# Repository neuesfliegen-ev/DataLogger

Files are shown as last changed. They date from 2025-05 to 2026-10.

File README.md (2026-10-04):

# 🛩️ Flight Data Logger

This project is a **Flight Data Logger** designed for UAVs and model aircraft. It logs sensor and GPS data at 1 Hz to an SD card in CSV format and streams live telemetry to a server over a cellular (3G/4G) link. The system uses an IMU, a barometric sensor and a GPS module, and shows live status updates on an OLED screen.

## 📦 Features

- Logs data to SD card in `.csv` format
- Captures:
  - 9-axis IMU data (acceleration, gyroscope, magnetometer)
  - Barometric pressure, altitude and temperature
  - GPS coordinates, altitude, speed and satellite count
- OLED display for live status updates
- **Live telemetry over cellular**: an ESP32 gateway forwards data to a web server through a SIM7600 modem (see [Live Telemetry](#-live-telemetry-esp32--sim7600))
- Live dashboard for the telemetry data
- Modular and extensible design for future sensor integration

## 🧠 Core Components

| Component | Description |
|---|---|
| **Arduino** | Primary microcontroller (Nano 33 BLE Sense REV2): sensors, SD logging, OLED |
| **ESP32** | Telemetry gateway between the Arduino and the cellular modem |
| **SIM7600** | Cellular modem (with SIM card), controlled by AT commands over UART |
| **BMI270_BMM150** | 9-DOF IMU (acceleration, gyroscope, magnetometer) |
| **LPS22HB** | Barometric pressure sensor |
| **TinyGPS++** | GPS data parser |
| **SH1106 OLED** | I2C 128x64 screen for live feedback |
| **SD Card Module**  | Stores `.csv` data logs |
| **Voltage Divider** | Scales down battery voltage for safe ADC reading |

---

## 📡 Live Telemetry (ESP32 + SIM7600)

Code: [`esp32SimNano.ino`](esp32SimNano.ino)

```
Arduino Nano ──I2C (JSON frames)──► ESP32 ──UART (AT commands)──► SIM7600 ──HTTP POST──► Server ──► Dashboard
     ▲                                │
     └────── READY / ACK (GPIO) ──────┘
```

- **Arduino → ESP32:** the ESP32 runs as an I2C slave (address `0x42`) and receives each data frame as a JSON payload.
- **Handshake:** two GPIO lines coordinate the transfer:
  - `READY` (ESP32 → Nano, GPIO 4): high when the modem is up and the ESP32 can accept a new frame.
  - `ACK` (ESP32 → Nano, GPIO 5): high when the last frame was delivered successfully (HTTP 200).
- **ESP32 → SIM7600:** UART2 at 115200 baud (ESP32 TX = GPIO 17, RX = GPIO 16). On startup the ESP32:
  1. waits until the modem answers `AT`
  2. disables echo (`ATE0`)
  3. opens the network (`AT+NETOPEN`)
  4. starts an HTTP session (`AT+HTTPINIT`, recovering with `AT+HTTPTERM` if a session is stuck)
  5. sets the server URL and `application/json` content type (`AT+HTTPPARA`)
- **Sending:** each frame is uploaded with `AT+HTTPDATA` and sent as an HTTP POST (`AT+HTTPACTION=1`). The ESP32 then waits for an HTTP 200 response.
- **Health check:** the ESP32 polls the modem with `AT` every 200 ms and updates the `READY` line.
- **Modes:** the payload carries a `"mode"` field (`REALTIME` or `BATCH`), which the ESP32 parses.

---

## 🔧 Circuit Diagram

[Wiring diagram](Datenlogger_Files/Datalogger_schematic%20v2.pdf)

> Note: the schematic still shows a 430 Ω resistor in the voltage divider. Use **510 Ω** as described below.

---

## 🔋 ADC Voltage Divider

To safely read the battery voltage with the Arduino's 3.3 V ADC pin, use the following voltage divider:

- **Input voltage**: up to 4.2 V (LiPo 1S max)
- **Top resistor (battery side)**: 510 Ω
- **Bottom resistor (to GND, ADC reads across it)**: 1.8 kΩ

### 📐 Voltage Divider Calculation

```
Vout = Vin × R_bottom / (R_top + R_bottom)
     = 4.2 V × 1800 / (510 + 1800)
     ≈ 3.27 V
```

---

## 📂 Data Format

Logged data is stored as a CSV file (`log.csv`) with the following headers:

```
timestamp,accX,accY,accZ,gyroX,gyroY,gyroZ,magX,magY,magZ,
latitude,longitude,gpsAltitude,Speed,SatCount,roll,pitch,yaw,
pressure,temperature,paltitude
```

Example row:

```
1542,-0.01,0.02,9.81,0.01,-0.02,0.00,30.12,11.23,-45.66,
52.5200,13.4050,120.5,10.4,9,0,0,0,100.3,25.5,132.2
```

---

## 🛠️ Getting Started

### 🔌 Wiring

- Connect sensors and modules via I2C/SPI/Serial as per the diagram.
- Ensure GPS is connected to `Serial1` (typically `TX`/`RX` on the Arduino). (IMPORTANT)
- For telemetry: connect the Arduino to the ESP32 over I2C plus the `READY`/`ACK` lines, and the ESP32 to the SIM7600 over UART (pins above). Insert an active SIM card.
- Insert a **FAT32-formatted SD card**.

### 🧪 Uploading

1. Install dependencies (Arduino):
   - `Arduino_BMI270_BMM150`
   - `Arduino_LPS22HB`
   - `TinyGPSPlus`
   - `U8g2`
2. Compile and upload the main sketch to the Arduino.
3. Upload `esp32SimNano.ino` to the ESP32 (ESP32 board package, uses `Wire` and `HardwareSerial`). Set the server URL in `initSIM7600()` if needed.
4. Open the Serial Monitor at **115200 baud** to see real-time debug info (the ESP32 also echoes modem responses there).

---

## 📊 OLED Display

The OLED shows system status:
- Sensor initialization
- GPS satellite count
- Errors during SD or sensor setup
- Team number

> To keep the display clear and reduce power, messages are brief and limited to startup and GPS updates.

---

## 🧩 Planned Improvements

- Add orientation calculation (roll, pitch, yaw)
- Support logging at configurable rates (5 Hz, 10 Hz)
- Add battery voltage and current sensors

---

## 👨‍💻 Credits

- Developed by the **Neues Fliegen Avionics Team**
- Based on libraries by Arduino, Adafruit and Mikal Hart (TinyGPS++)

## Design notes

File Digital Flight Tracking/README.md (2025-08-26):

# 3D Flight Viewer

An interactive 3D flight path visualization tool that displays animated aircraft flight paths with real-time attitude data, G-force analysis, and speed visualization. [Example video is shot using "flight6.CSV"]

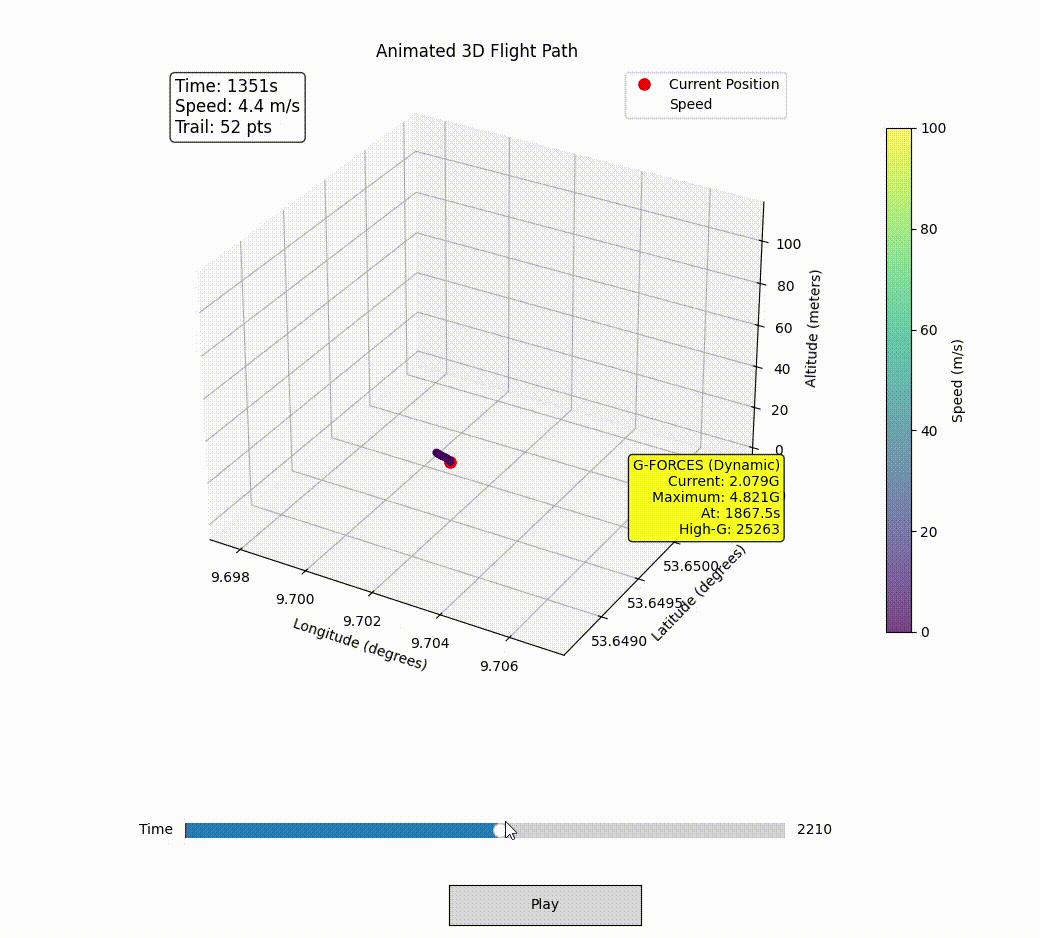
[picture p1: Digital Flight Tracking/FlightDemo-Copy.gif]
GIF


## Features

- **Interactive 3D Animation**: Real-time flight path with speed-colored trail
- **Flight Controls**: Play/pause, time slider for navigation
- **Attitude Analysis**: Roll, pitch, yaw calculations with aviation standards
- **G-Force Monitoring**: Dynamic G-force analysis with high-G event detection
- **Multiple Data Sources**: Support for various flight data formats
- **Click Interaction**: Click on flight path to view detailed flight parameters

## Prerequisites

### Required Software
- **Python 3.7+** (recommended: Python 3.9 or newer)
- **IDE Options** (any of these work well):
  - Visual Studio Code
  - PyCharm
  - Windsurf IDE
  - Jupyter Notebook
  - Any Python-compatible IDE

### Dependencies
Install the required Python packages:

```bash
pip install -r requirements.txt
```

**Required packages:**
- `pandas>=1.3.0` - Data manipulation and analysis
- `numpy>=1.20.0` - Numerical computations
- `matplotlib>=3.3.0` - 3D plotting and animation
- `openpyxl>=3.0.0` - Excel file support
- `pyglet>=1.5.0` - Graphics library

## Installation

1. **Clone or download** the flight_viewer directory
2. **Navigate to the flight_viewer folder** in your terminal/command prompt
3. **Install dependencies:**
   ```bash
   pip install -r requirements.txt
   ```

## Usage

### Basic Usage (Default Flight)
```bash
python animated_3d_viewer.py
```
This runs the default flight data (`ATA-Flight2.CSV`).

### Run Specific Flight Files
You can specify different flight files by adding the filename:

```bash
python animated_3d_viewer.py [filename.CSV]
```

### Available Example Flights
The following flight files are included:

```bash
# Team flights
python animated_3d_viewer.py flight1.CSV      # Default
python animated_3d_viewer.py flight2.CSV
python animated_3d_viewer.py flight3.CSV
python animated_3d_viewer.py flight4.CSV
python animated_3d_viewer.py flight5.CSV
python animated_3d_viewer.py flight6.CSV
```

## Required CSV Format

Your flight data CSV must contain these columns:
- `timestamp` - Time in milliseconds
- `latitude` - GPS latitude in degrees
- `longitude` - GPS longitude in degrees
- `altitude` or `gpsAltitude` - Altitude in meters

**Optional columns for enhanced features:**
- `accX`, `accY`, `accZ` - Accelerometer data (G-units)
- `gyroX`, `gyroY`, `gyroZ` - Gyroscope data (degrees/second)

## Controls

### Animation Controls
- **Play/Pause Button** - Start/stop the animation
- **Time Slider** - Drag to jump to any point in the flight
- **Mouse Click** - Click on flight path points to view detailed data

### Keyboard Shortcuts
- **Close Window** - End the visualization

## Flight Data Display

The viewer shows:
- **Current Position** - Red marker showing aircraft location
- **Speed Trail** - Color-coded trail (51 points) showing recent flight path
  - Blue/Purple = Slower speeds
  - Green/Yellow = Medium speeds  
  - Red = Higher speeds
- **Flight Info Panel** - Current time, speed, and trail length
- **G-Force Panel** - Real-time and maximum G-force data
- **Clickable Points** - Click any trail point for detailed flight parameters

## Performance Features

- **3x Speed Animation** - Fast playback through flight data
- **Optimized Rendering** - Reduced lag with efficient trail rendering
- **Smart Data Sampling** - Shows every 6th data point for smooth performance

## Troubleshooting

### File Not Found
```
Error: File 'filename.CSV' not found.
```
- Ensure you're running the command from the `flight_viewer` directory
- Check that the CSV file exists in the same folder
- Use the exact filename (case-sensitive)

### Missing Columns
The program will show available columns if required ones are missing:
```
Available columns: ['col1', 'col2', ...]
Missing required column 'latitude'. Looked for: ['latitude']
```

### Performance Issues
- Close other applications to free up system resources
- Try a smaller flight file for testing
- Ensure your graphics drivers are up to date

## File Structure

```
flight_viewer/
├── animated_3d_viewer.py    # Main application
├── data_loader.py           # CSV/Excel file reading
├── requirements.txt         # Python dependencies
├── README.md                # This documentation
├── flight1.CSV              # Default flight data
├── flight2.CSV              # Example flight files
├── flight3.CSV              # ...
├── flight4.CSV              # ...
├── flight5.CSV              # ...
├── flight6.CSV              # ...
└── [other flight files]     # Additional examples
```

## Example Commands

```bash
# Run with default settings
python animated_3d_viewer.py

# Run specific team flights
python animated_3d_viewer.py flight6.CSV
python animated_3d_viewer.py flight4.CSV

# Run your own flight data
python animated_3d_viewer.py my_flight_data.CSV
```

## Technical Details

- **Coordinate System**: Uses GPS coordinates (latitude, longitude, altitude)
- **Animation Speed**: 3x real-time with 8ms frame intervals
- **Trail Length**: 51 points with speed-based coloring
- **Attitude Calculation**: Team 0 configuration with aviation standards
- **G-Force Analysis**: Dynamic G-force with gravity compensation

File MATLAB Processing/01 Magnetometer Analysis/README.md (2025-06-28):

# Application of a Kalman Filter for robustness and precision

The following program can be obtained running "A00_Kalman_Filter_TXTs.m", part of the project "01 Final Analysis \ 00 Ideal Spherical Calibration". It includes hard-iron and soft-iron corrections, and accounts for severe magnetic field spikes possibly caused by temporary surrounding objects.

The data used to make the analysis is transferred directly from the USB powering the Arduino, and captured through a simple Windows PowerShell program, "00_ReadUSB_toTxt.ps1". The .ino file is also adapted for this purpose and all necessary files can be found in the folder "02 General Purpose Programs".

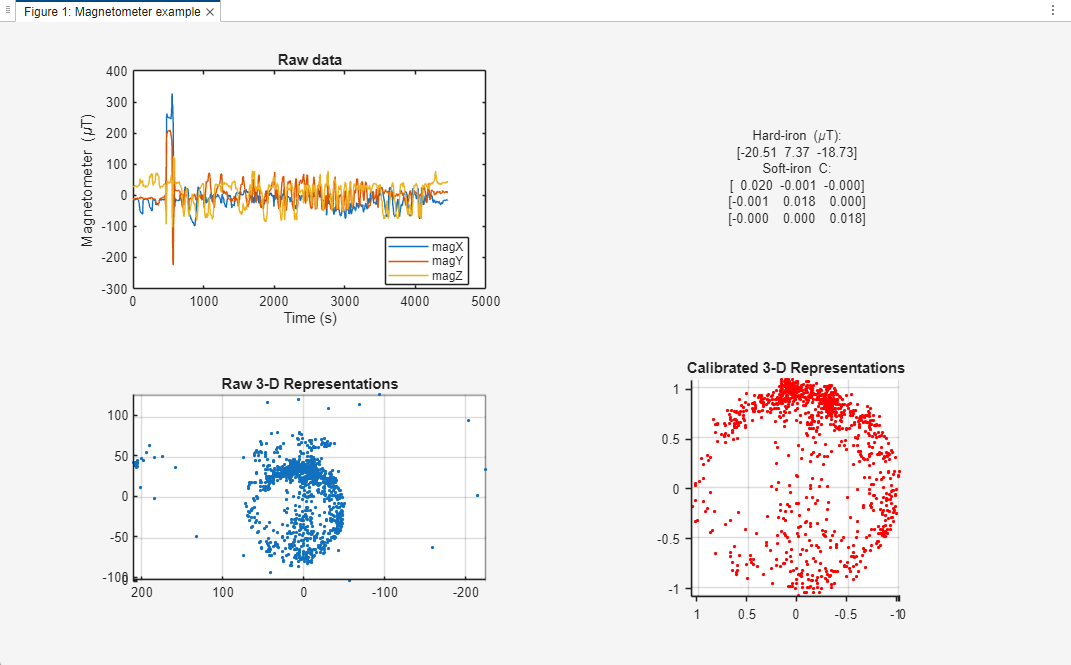
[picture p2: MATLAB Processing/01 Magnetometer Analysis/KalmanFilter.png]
Magnetometer


# Suggested Calibration Procedure

The most realistic and somewhat accurate calibrations are rather the complicated Six-Axis Calibration or the Two-Axis Calibration. The latter still leads to fairly accurate measurements, and is advisable for the competition if "yaw" isn't a critical quantity.

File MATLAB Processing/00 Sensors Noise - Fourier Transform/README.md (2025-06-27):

# Fourier Transform for noise analysis

The following data can be obtained running the main program 'A02_Multiple_SensorData_Analysis'. All other files are functions and must be inside the same folder (including the Excel sheet).

## 📌 Original Signals

Below are the unmodified signals, recorded for 8hs without movement (stationary data collection).

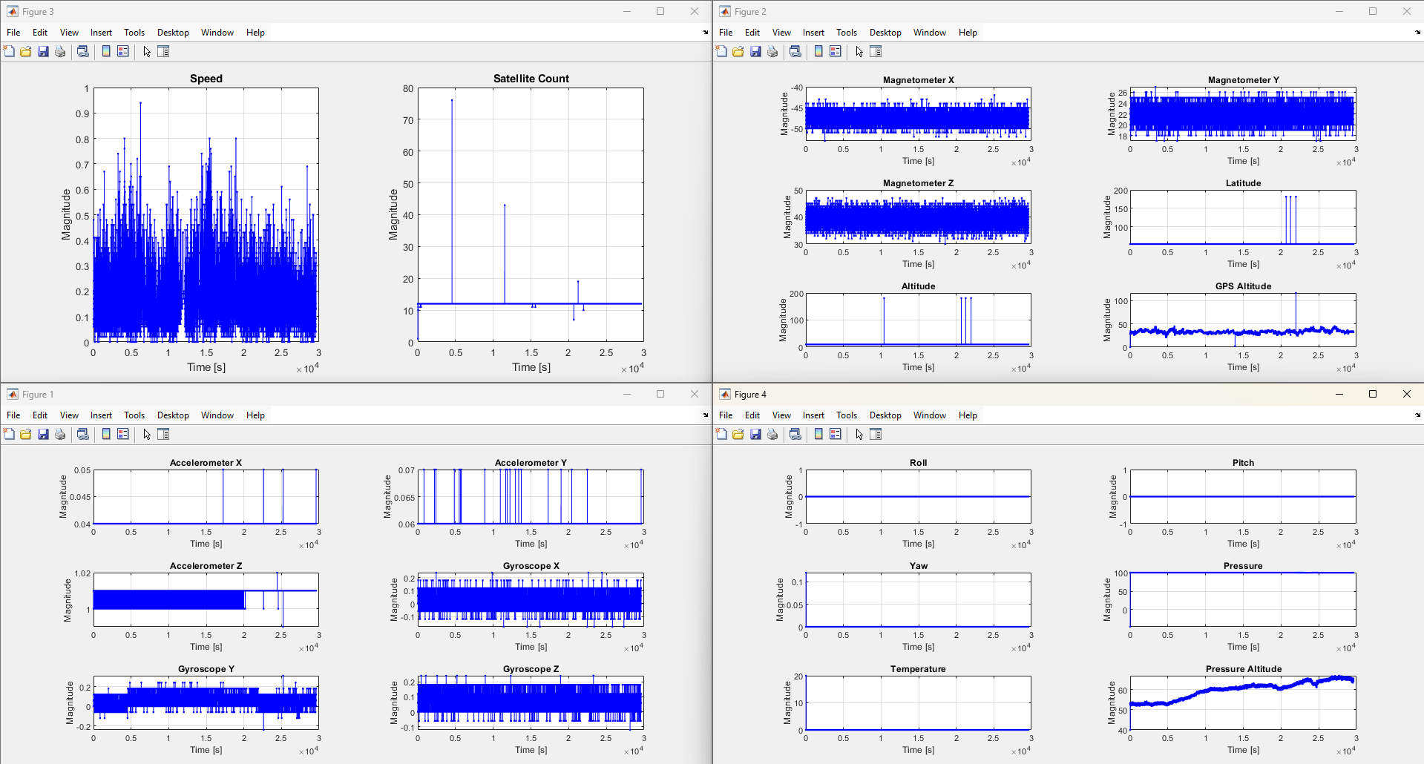
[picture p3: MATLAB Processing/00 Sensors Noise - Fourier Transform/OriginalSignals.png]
Original


## 📌 Fourier Transforms of the signals

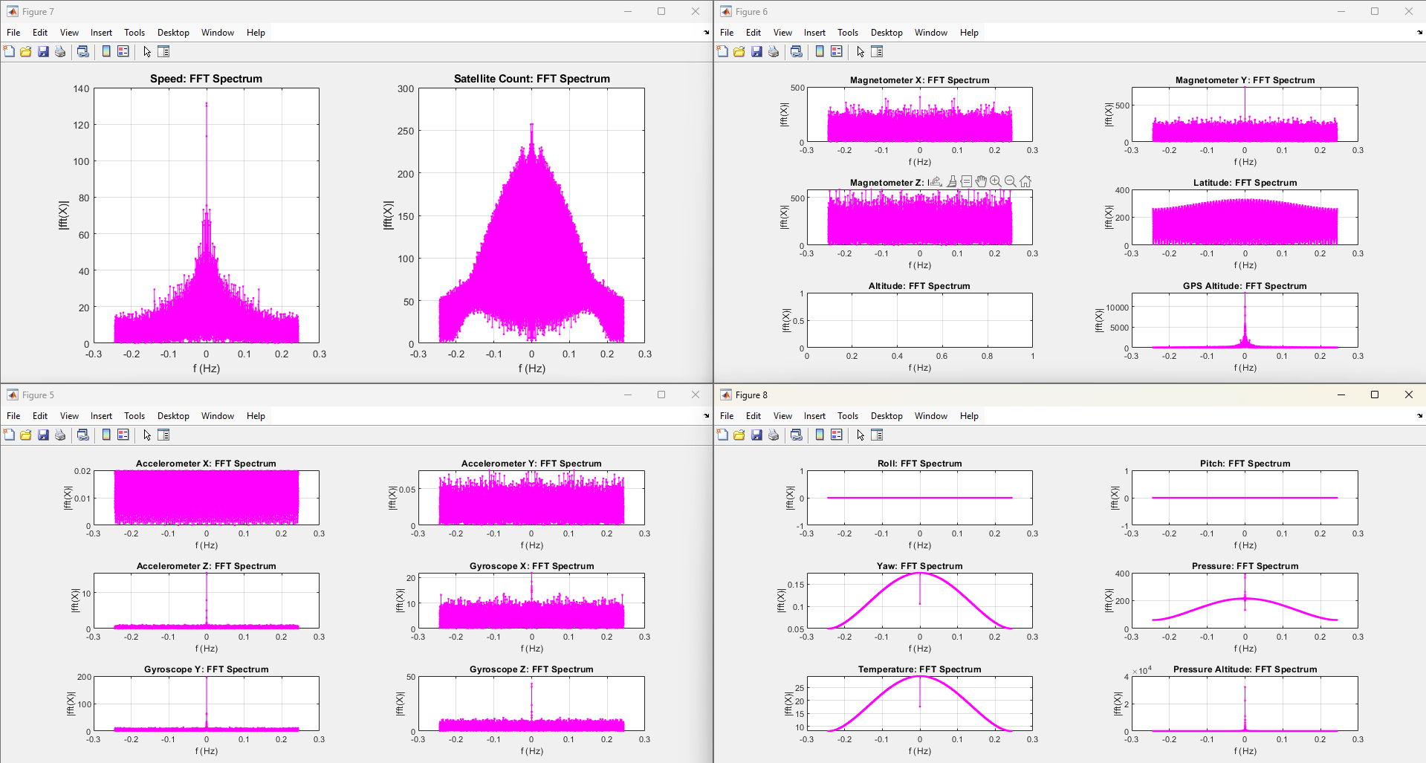
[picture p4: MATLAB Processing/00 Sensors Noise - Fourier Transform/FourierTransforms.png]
FFT


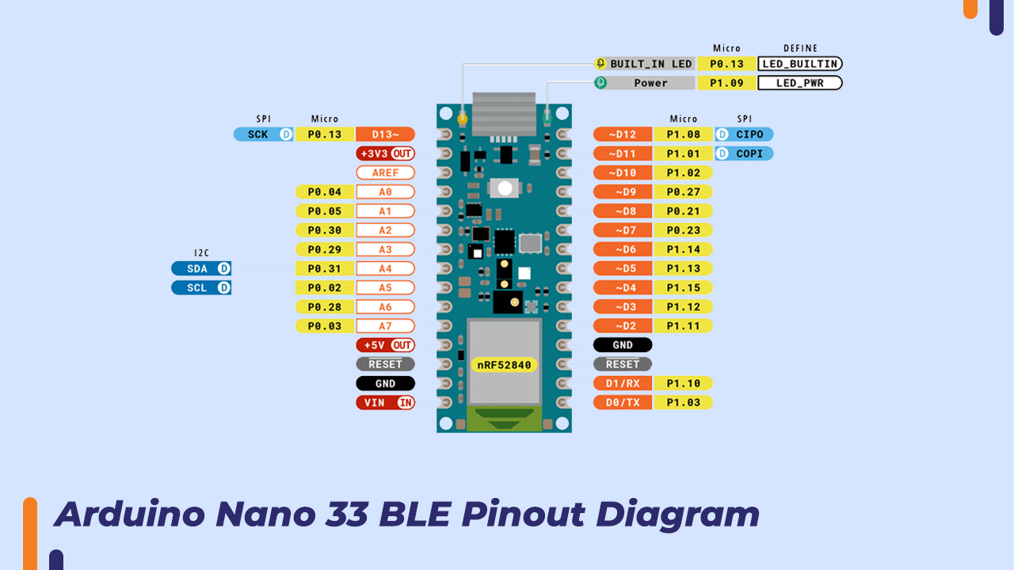
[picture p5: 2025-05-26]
Documentation/Arduino-Nano-33-BLE-Sense-REV2-pinout-diagram.jpg

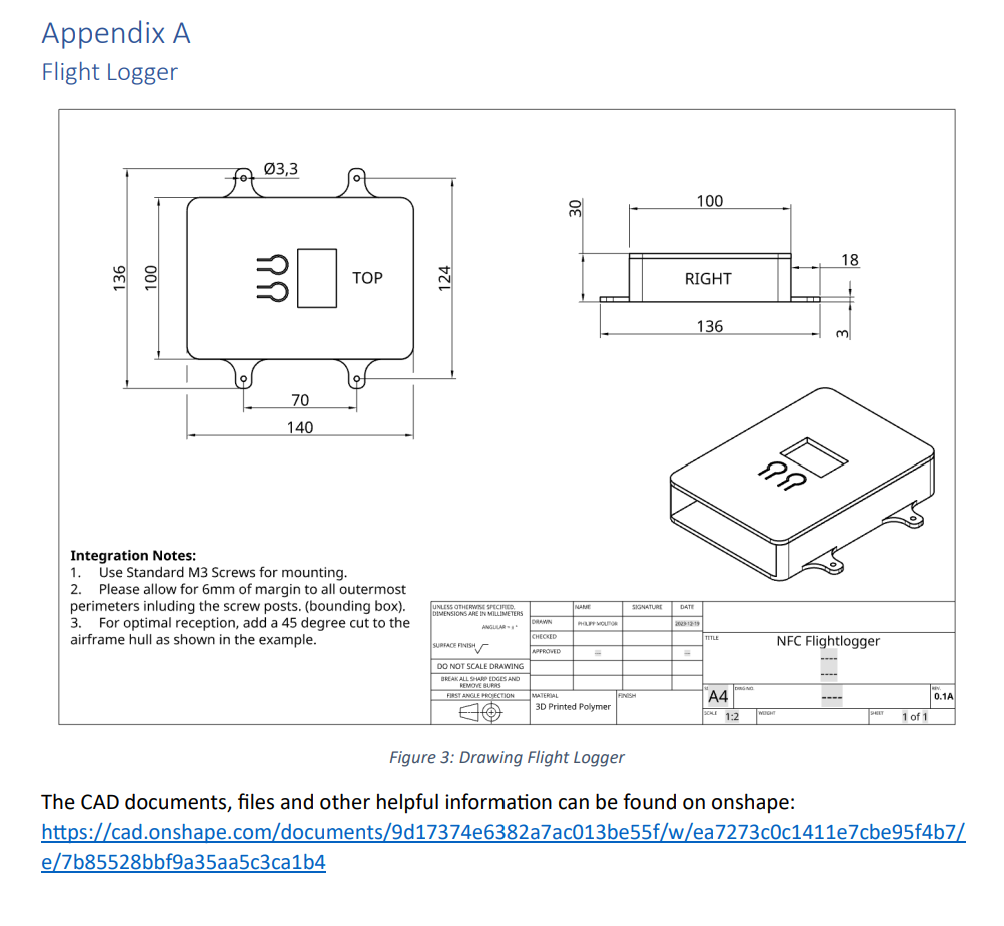
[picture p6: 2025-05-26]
Documentation/Screenshot 2025-05-26 195449.png

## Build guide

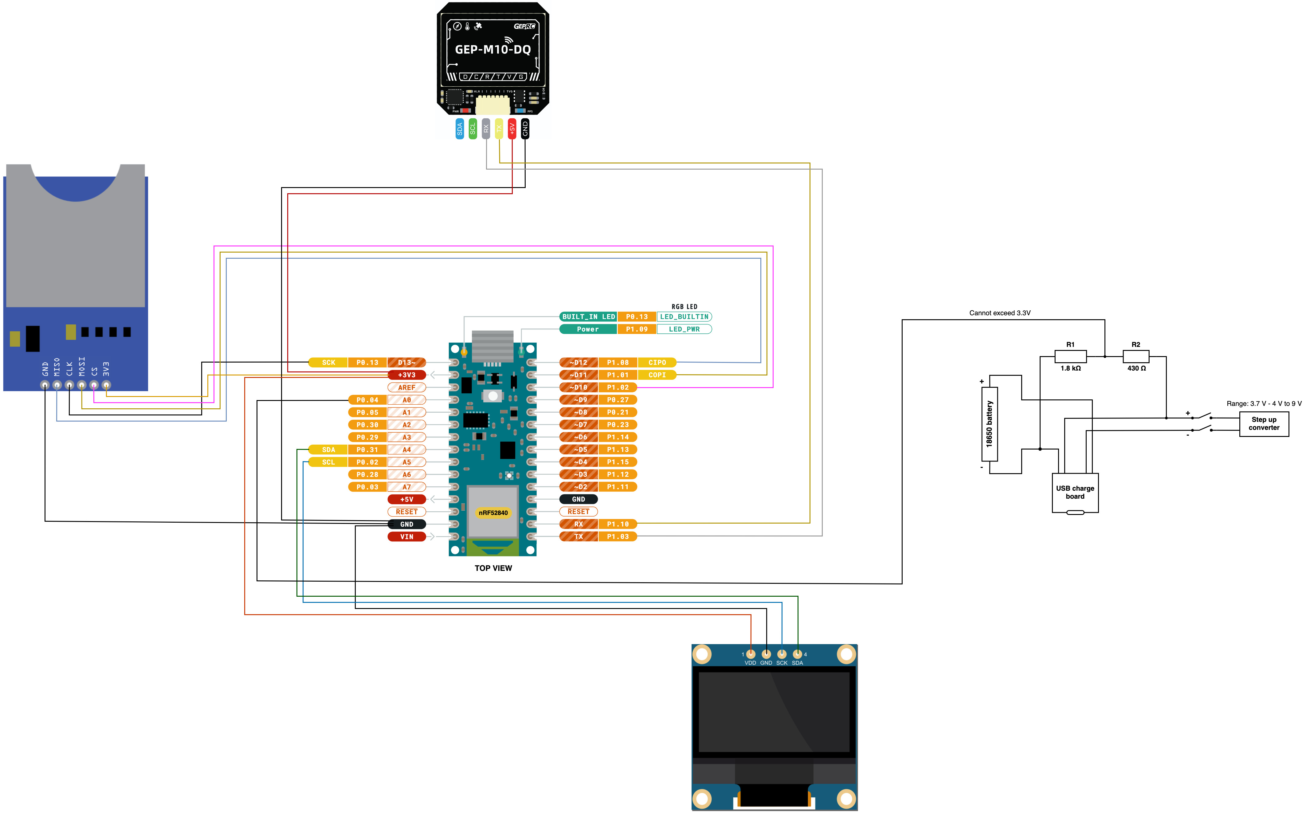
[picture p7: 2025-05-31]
Documentation/Wiring_diagram_1.1.jpg

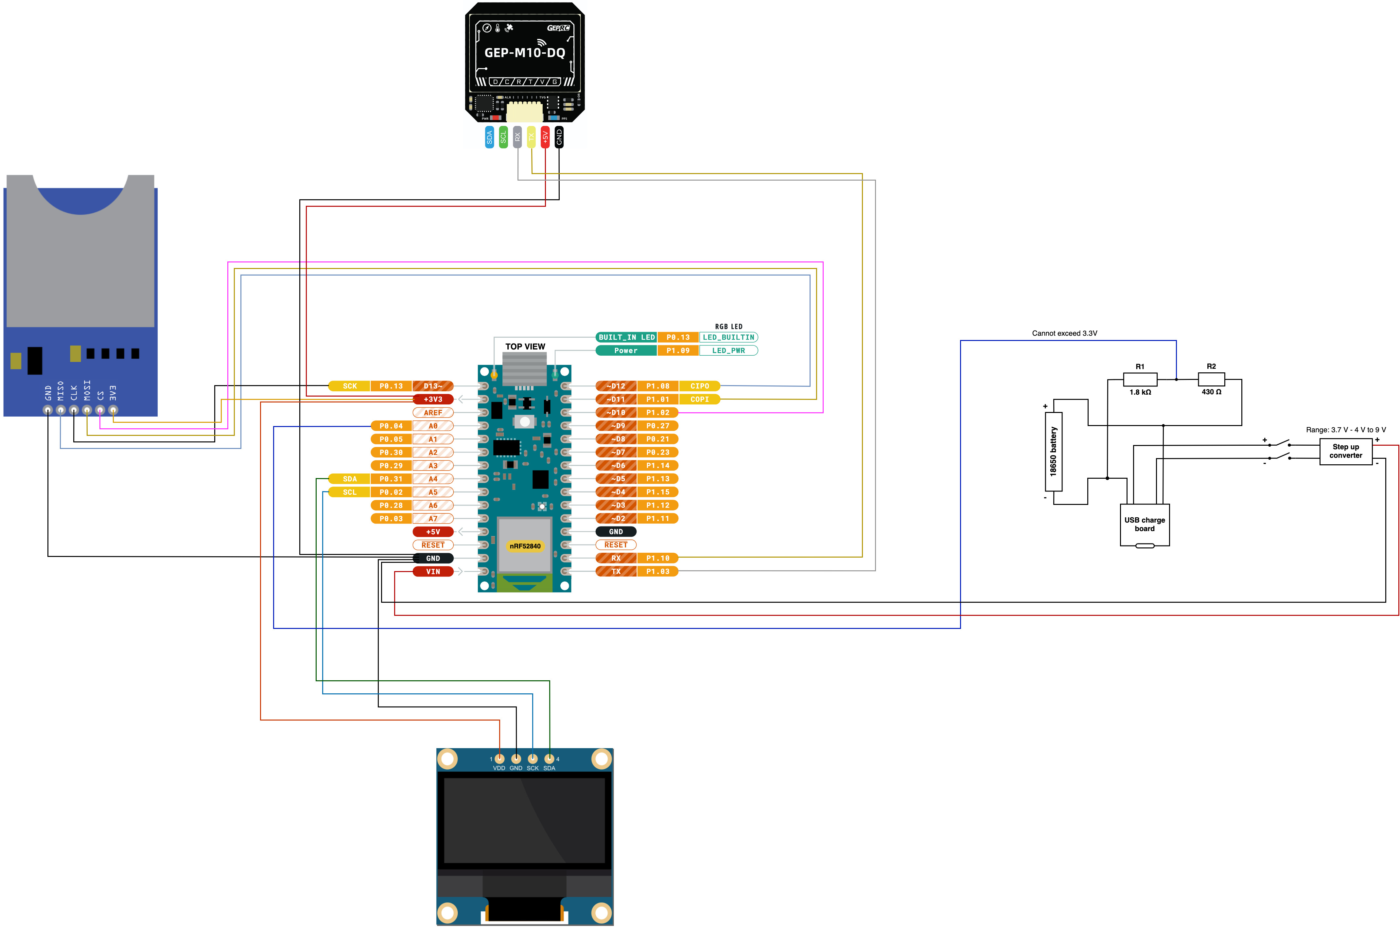
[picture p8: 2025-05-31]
Documentation/Wiring_diagram_1.2.jpg

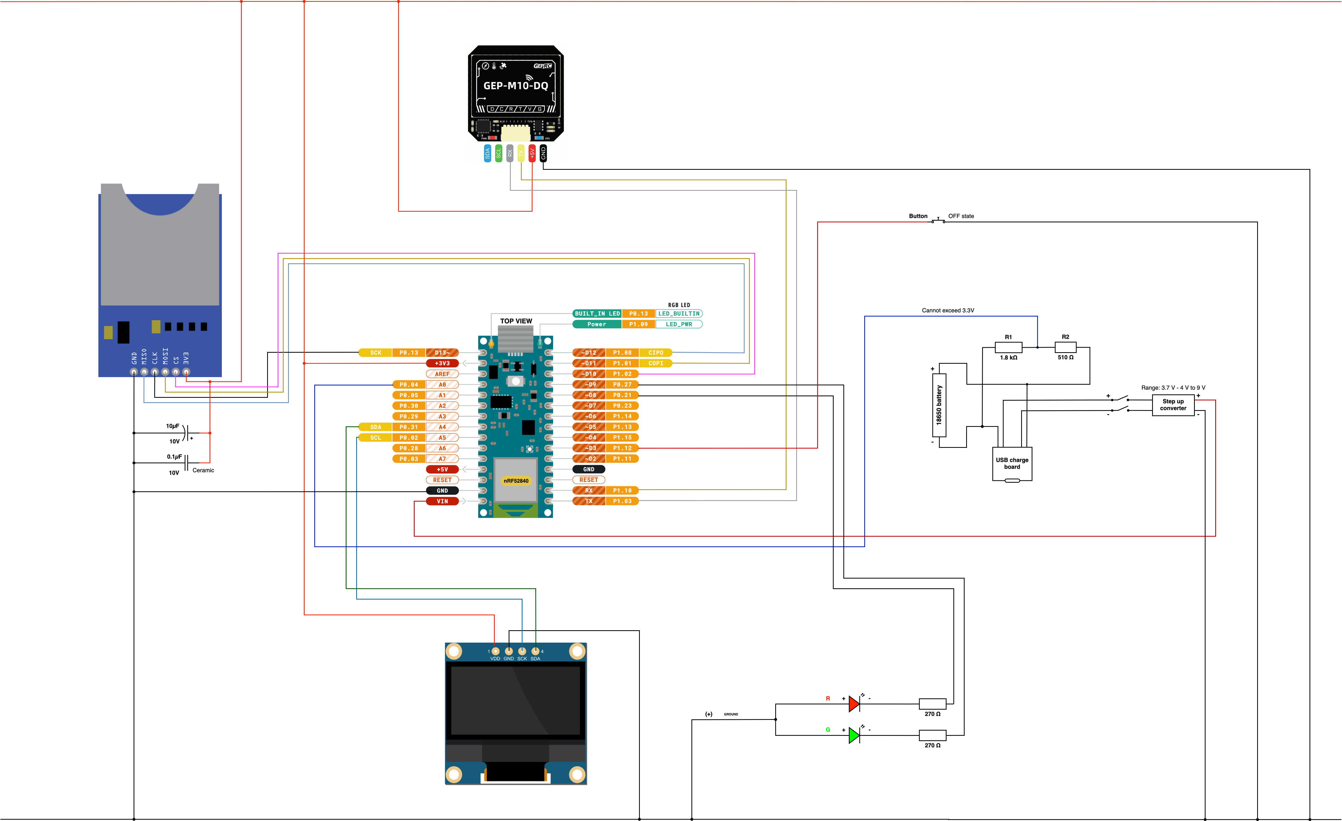
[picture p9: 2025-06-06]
Documentation/Wiring_diagram_1.3.jpg

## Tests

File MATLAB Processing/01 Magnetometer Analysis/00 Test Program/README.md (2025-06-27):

# Application of a Kalman Filter for robustness and precision

The following program can be obtained running "A00_Kalman_Filter_Offline.m". It takes sample data from existing flights, without initial calibrations. The initial idea was an on-flight filtering.

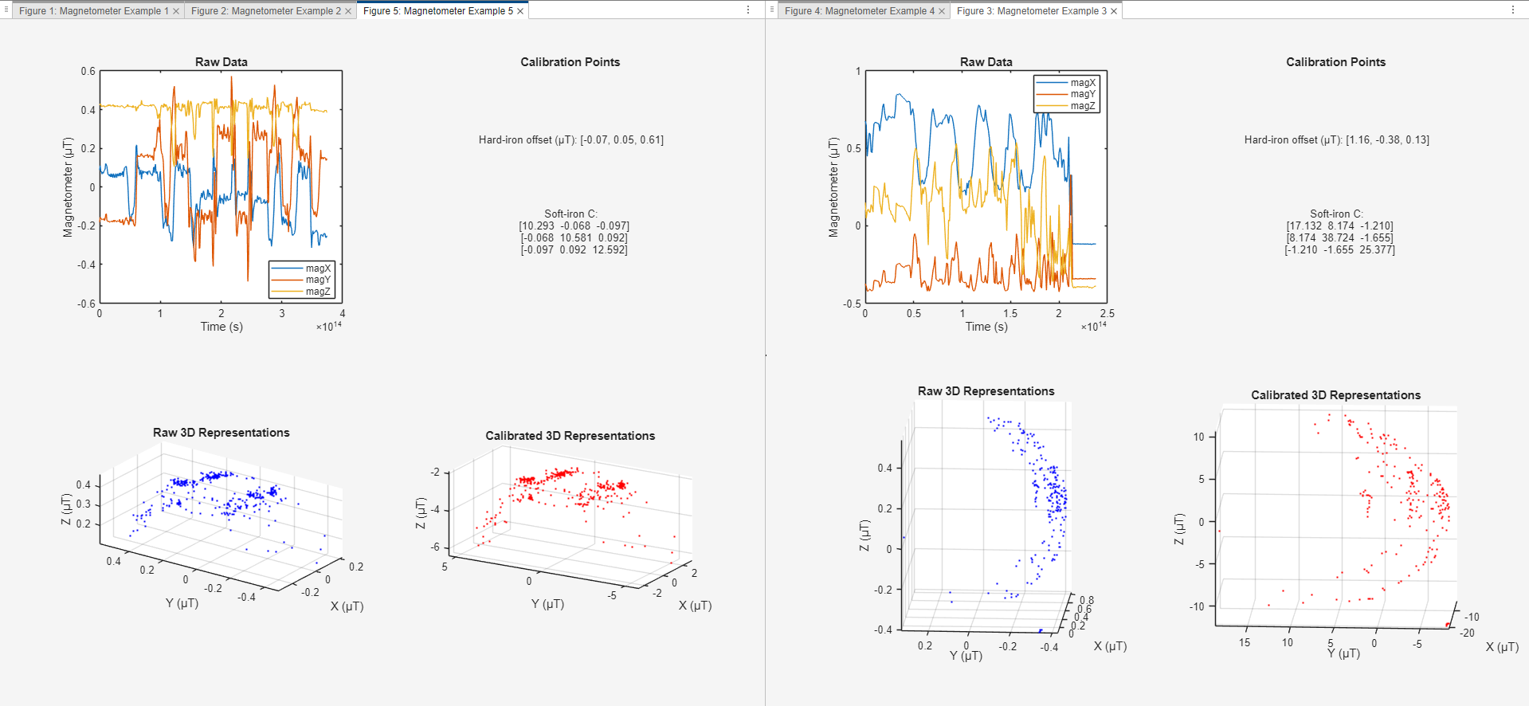
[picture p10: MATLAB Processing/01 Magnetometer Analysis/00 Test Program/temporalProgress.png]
Magnetometer


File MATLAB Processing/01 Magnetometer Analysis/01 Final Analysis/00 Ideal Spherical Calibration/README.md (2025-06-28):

## Ideal Spherical Calibration

This method executes hard-iron and soft-iron corrections, and it is the most precise among all. However, capturing the data necessary to calibrate this is extremely complex for our purpose.

The calibration process should be done with the datalogger inside the plane, and rotating the aircraft in all possible positions reaching an almost full 3D spherical collection of data. It's is not feasible.

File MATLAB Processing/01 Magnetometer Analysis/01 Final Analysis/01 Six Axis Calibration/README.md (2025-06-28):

## Six Axis Calibration

This method executes only a hard-iron calibration, which accounts for > 90% of the errors in pitch, roll, and yaw.

## Procedure

1. Place the datalogger inside the plane.
2. Position the aircraft in 6 different positions covering +x, -x, +y, -y, +z, -z.
3. Hold each position for 3 seconds.

## Results

This method is slightly inconvenient but improves leads to the following outcomes:
	- Yaw: -+ 5° error magin.
	- Improved roll and pitch measurements, although not strictly dependent to the magnetometer.

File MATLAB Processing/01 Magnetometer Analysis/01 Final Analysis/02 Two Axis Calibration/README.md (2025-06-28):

## Two Axis Calibration

This method executes only an XY hard-iron calibration. Hard-iron offsets are the main source of error, and leaving the Z axis uncalibrated affects the error margin of Yaw.

# Procedure

1. Place the datalogger inside the plane.
2. Slowly rotate the aircraft 360° in a flat surface (or by hand) for ~30 seconds.

# Results

Yaw error margin: -+ 9°

Skipping the two-axis magnetometer calibration, on the other hand, would lead to yaw errors of -+ 15-30°

# Analysis of the Screenshot

This method correct XY offsets. Even though the Z looks calibrated as well, that is mainly because there were no significant Z offsets during this measurements (this is not likely to be the case during the competition).

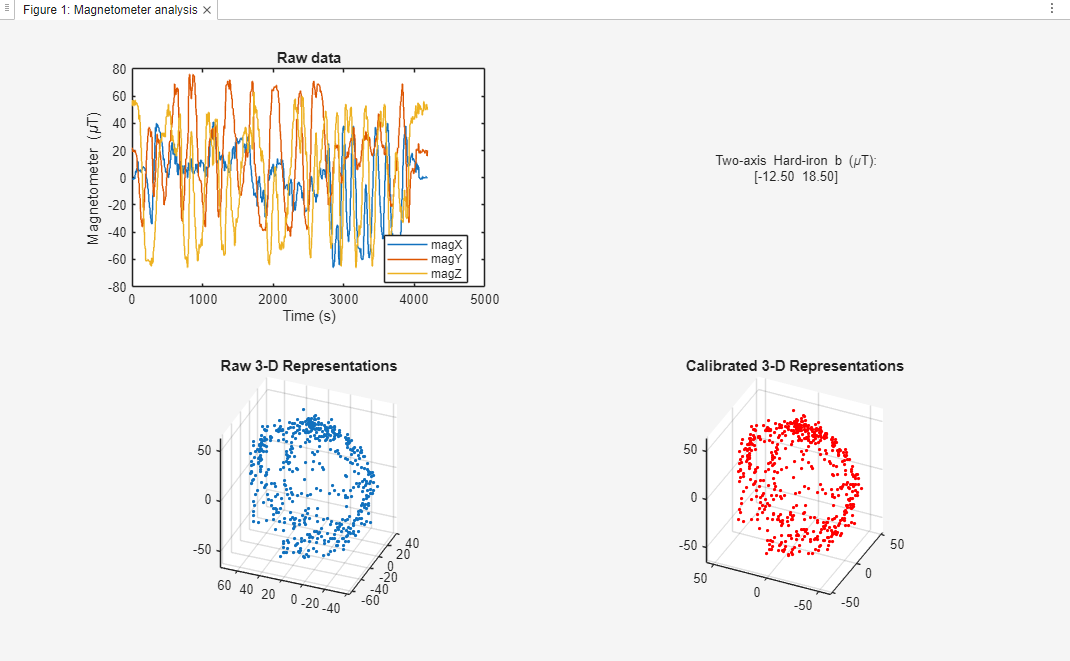
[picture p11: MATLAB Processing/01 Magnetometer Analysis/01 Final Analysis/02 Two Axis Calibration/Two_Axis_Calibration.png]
TwoAxis


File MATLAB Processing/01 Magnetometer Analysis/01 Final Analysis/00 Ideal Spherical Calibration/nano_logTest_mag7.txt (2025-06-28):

IMU calibration complete.
IMU initialized successfully!
Ready to start!!
Waiting for button to start logging...
New Logging is starting!

magX,magY,magZ

-18.00,-10.00,25.00

-18.00,-10.00,25.00

-18.00,-10.00,25.00

-18.00,-11.00,28.00

-18.00,-11.00,28.00

-18.00,-11.00,28.00

-21.00,-8.00,27.00

-21.00,-8.00,27.00

-21.00,-8.00,27.00

-21.00,-8.00,27.00

-21.00,-8.00,27.00

-21.00,-8.00,27.00

-21.00,-8.00,27.00

-23.00,-9.00,28.00

-23.00,-9.00,28.00

-23.00,-9.00,28.00

-22.00,-9.00,30.00

-22.00,-9.00,30.00

-22.00,-9.00,30.00

-22.00,-7.00,27.00

-22.00,-7.00,27.00

-22.00,-7.00,27.00

-22.00,-7.00,27.00

-22.00,-8.00,28.00

-22.00,-8.00,28.00

-22.00,-8.00,28.00

-19.00,-10.00,35.00

-19.00,-10.00,35.00

-19.00,-10.00,35.00

-19.00,-10.00,35.00

-22.00,-8.00,29.00

-22.00,-8.00,29.00

-22.00,-8.00,29.00

-22.00,-8.00,27.00

-22.00,-8.00,27.00

-22.00,-8.00,27.00

-20.00,-12.00,30.00

-20.00,-12.00,30.00

-20.00,-12.00,30.00

-20.00,-12.00,30.00

-21.00,-10.00,25.00

-21.00,-10.00,25.00

-21.00,-10.00,25.00

-15.00,-10.00,26.00

-15.00,-10.00,26.00

-15.00,-10.00,26.00

-5.00,-11.00,26.00

-5.00,-11.00,26.00

-5.00,-11.00,26.00

-5.00,-11.00,26.00

-16.00,-11.00,30.00

-16.00,-11.00,30.00

-16.00,-11.00,30.00

-32.00,-14.00,25.00

-32.00,-14.00,25.00

-32.00,-14.00,25.00

-32.00,-14.00,25.00

-39.00,-14.00,20.00

-39.00,-14.00,20.00

-39.00,-14.00,20.00

-47.00,-15.00,18.00

-47.00,-15.00,18.00

-47.00,-15.00,18.00

-56.00,-12.00,12.00

-56.00,-12.00,12.00

-56.00,-12.00,12.00

-56.00,-12.00,12.00

-56.00,-19.00,10.00

-56.00,-19.00,10.00

-56.00,-19.00,10.00

-48.00,-13.00,20.00

-48.00,-13.00,20.00

-48.00,-13.00,20.00

-22.00,-16.00,31.00

-22.00,-16.00,31.00

-22.00,-16.00,31.00

-22.00,-16.00,31.00

-11.00,-14.00,25.00

-11.00,-14.00,25.00

-11.00,-14.00,25.00

8.00,-10.00,18.00

8.00,-10.00,18.00

8.00,-10.00,18.00

8.00,-10.00,18.00

10.00,-6.00,18.00

10.00,-6.00,18.00

10.00,-6.00,18.00

5.00,-8.00,19.00

5.00,-8.00,19.00

5.00,-8.00,19.00

1.00,-6.00,27.00

1.00,-6.00,27.00

1.00,-6.00,27.00

1.00,-6.00,27.00

-8.00,-9.00,30.00

-8.00,-9.00,30.00

-8.00,-9.00,30.00

-13.00,-9.00,28.00

-13.00,-9.00,28.00

-13.00,-9.00,28.00

-13.00,-9.00,28.00

-15.00,-9.00,33.00

-15.00,-9.00,33.00

-15.00,-9.00,33.00

-15.00,-14.00,27.00

-15.00,-14.00,27.00

-15.00,-14.00,27.00

-14.00,-10.00,29.00

-14.00,-10.00,29.00

-14.00,-10.00,29.00

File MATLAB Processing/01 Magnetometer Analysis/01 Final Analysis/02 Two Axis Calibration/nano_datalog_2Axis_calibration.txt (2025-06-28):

IMU calibration complete.
IMU initialized successfully!
Ready to start!!
Waiting for button to start the program...
New Logging is starting!

magX,magY,magZ

-2.00,25.00,57.00

-2.00,25.00,57.00

-2.00,25.00,57.00

-2.00,25.00,57.00

-4.00,25.00,57.00

-4.00,25.00,57.00

-4.00,25.00,57.00

-4.00,25.00,57.00

-4.00,25.00,57.00

-4.00,25.00,57.00

-4.00,25.00,57.00

-4.00,25.00,57.00

-4.00,24.00,54.00

-4.00,24.00,54.00

-4.00,24.00,54.00

-4.00,24.00,54.00

-4.00,24.00,54.00

-4.00,24.00,54.00

-4.00,24.00,54.00

-2.00,24.00,56.00

-2.00,24.00,56.00

-2.00,24.00,56.00

-2.00,24.00,56.00

-2.00,24.00,56.00

-2.00,24.00,56.00

-2.00,24.00,56.00

-2.00,24.00,56.00

-1.00,27.00,57.00

-1.00,27.00,57.00

-1.00,27.00,57.00

-1.00,27.00,57.00

-1.00,27.00,57.00

-1.00,27.00,57.00

-1.00,27.00,57.00

-3.00,28.00,62.00

-3.00,28.00,62.00

-3.00,28.00,62.00

-3.00,28.00,62.00

-3.00,28.00,62.00

-3.00,28.00,62.00

-3.00,28.00,62.00

-2.00,24.00,57.00

-2.00,24.00,57.00

-2.00,24.00,57.00

-2.00,24.00,57.00

-2.00,24.00,57.00

-2.00,24.00,57.00

-2.00,24.00,57.00

-2.00,24.00,57.00

-2.00,24.00,57.00

-2.00,24.00,57.00

-2.00,25.00,55.00

-2.00,25.00,55.00

-2.00,25.00,55.00

-2.00,25.00,55.00

-2.00,25.00,55.00

-2.00,25.00,55.00

-2.00,25.00,55.00

-2.00,25.00,55.00

-3.00,25.00,54.00

-3.00,25.00,54.00

-3.00,25.00,54.00

-3.00,25.00,54.00

-3.00,25.00,54.00

-3.00,25.00,54.00

-3.00,25.00,54.00

-4.00,24.00,55.00

-4.00,24.00,55.00

-4.00,24.00,55.00

-4.00,24.00,55.00

-4.00,24.00,55.00

-4.00,24.00,55.00

-4.00,24.00,55.00

-4.00,24.00,55.00

-2.00,23.00,58.00

-2.00,23.00,58.00

-2.00,23.00,58.00

-2.00,23.00,58.00

-2.00,23.00,58.00

-2.00,23.00,58.00

-2.00,23.00,58.00

-4.00,25.00,59.00

-4.00,25.00,59.00

-4.00,25.00,59.00

-4.00,25.00,59.00

-4.00,25.00,59.00

-4.00,25.00,59.00

-4.00,25.00,59.00

-4.00,25.00,59.00

-4.00,24.00,57.00

-4.00,24.00,57.00

-4.00,24.00,57.00

-4.00,24.00,57.00

-4.00,24.00,57.00

-4.00,24.00,57.00

-4.00,24.00,57.00

-4.00,22.00,59.00

-4.00,22.00,59.00

-4.00,22.00,59.00

-4.00,22.00,59.00

-4.00,22.00,59.00

-4.00,22.00,59.00

-4.00,22.00,59.00

-2.00,24.00,59.00

-2.00,24.00,59.00

-2.00,24.00,59.00

-2.00,24.00,59.00

-2.00,24.00,59.00

-2.00,24.00,59.00

-2.00,24.00,59.00

-2.00,24.00,59.00

-4.00,26.00,59.00

-4.00,26.00,59.00

-4.00,26.00,59.00

-4.00,26.00,59.00

-4.00,26.00,59.00

-4.00,26.00,59.00

-4.00,26.00,59.00

-3.00,25.00,57.00

-3.00,25.00,57.00

-3.00,25.00,57.00

-3.00,25.00,57.00

-3.00,25.00,57.00

-3.00,25.00,57.00

-3.00,25.00,57.00

-3.00,25.00,57.00

-4.00,26.00,56.00

-4.00,26.00,56.00

-4.00,26.00,56.00

-4.00,26.00,56.00

-4.00,26.00,56.00

-4.00,26.00,56.00

-4.00,26.00,56.00

-4.00,26.00,56.00

-4.00,26.00,56.00

-4.00,26.00,56.00

-2.00,24.00,57.00

-2.00,24.00,57.00

-2.00,24.00,57.00

-2.00,24.00,57.00

-2.00,24.00,57.00

-2.00,24.00,57.00

-2.00,24.00,57.00

-2.00,24.00,57.00

0.00,25.00,55.00

0.00,25.00,55.00

0.00,25.00,55.00

0.00,25.00,55.00

0.00,25.00,55.00

0.00,25.00,55.00

0.00,25.00,55.00

-1.00,25.00,55.00

-1.00,25.00,55.00

-1.00,25.00,55.00

-1.00,25.00,55.00

-1.00,25.00,55.00

-1.00,25.00,55.00

-1.00,25.00,55.00

-1.00,25.00,55.00

-3.00,24.00,58.00

-3.00,24.00,58.00

-3.00,24.00,58.00

-3.00,24.00,58.00

-3.00,24.00,58.00

-3.00,24.00,58.00

-3.00,24.00,58.00

-3.00,24.00,58.00

-4.00,26.00,55.00

-4.00,26.00,55.00

-4.00,26.00,55.00

-4.00,26.00,55.00

-4.00,26.00,55.00

-4.00,26.00,55.00

-4.00,26.00,55.00

-4.00,26.00,56.00

-4.00,26.00,56.00

-4.00,26.00,56.00

-4.00,26.00,56.00

-4.00,26.00,56.00

-4.00,26.00,56.00

-4.00,26.00,56.00

-5.00,27.00,59.00

-5.00,27.00,59.00

-5.00,27.00,59.00

-5.00,27.00,59.00

-5.00,27.00,59.00

-5.00,27.00,59.00

-5.00,27.00,59.00

-5.00,27.00,59.00

-9.00,30.00,55.00

-9.00,30.00,55.00

-9.00,30.00,55.00

-9.00,30.00,55.00

-9.00,30.00,55.00

-9.00,30.00,55.00

-9.00,30.00,55.00

-13.00,32.00,50.00

-13.00,32.00,50.00

-13.00,32.00,50.00

-13.00,32.00,50.00

-13.00,32.00,50.00

-13.00,32.00,50.00

-13.00,32.00,50.00

-13.00,32.00,50.00

-18.00,31.00,48.00

-18.00,31.00,48.00

-18.00,31.00,48.00

-18.00,31.00,48.00

-18.00,31.00,48.00

-18.00,31.00,48.00

-18.00,31.00,48.00

-18.00,31.00,48.00

-22.00,29.00,30.00

-22.00,29.00,30.00

-22.00,29.00,30.00

-22.00,29.00,30.00

-22.00,29.00,30.00

-22.00,29.00,30.00

-22.00,29.00,30.00

-19.00,31.00,15.00

-19.00,31.00,15.00

-19.00,31.00,15.00

-19.00,31.00,15.00

-19.00,31.00,15.00

-19.00,31.00,15.00

-19.00,31.00,15.00

-19.00,31.00,15.00

-19.00,24.00,17.00

-19.00,24.00,17.00

-19.00,24.00,17.00

-19.00,24.00,17.00

-19.00,24.00,17.00

-19.00,24.00,17.00

-19.00,24.00,17.00

-16.00,22.00,16.00

-16.00,22.00,16.00

-16.00,22.00,16.00

-16.00,22.00,16.00

-16.00,22.00,16.00

-16.00,22.00,16.00

-16.00,22.00,16.00

-16.00,22.00,16.00

-10.00,22.00,13.00

-10.00,22.00,13.00

-10.00,22.00,13.00

-10.00,22.00,13.00

-10.00,22.00,13.00

-10.00,22.00,13.00

-10.00,22.00,13.00

-4.00,20.00,21.00

-4.00,20.00,21.00

-4.00,20.00,21.00

-4.00,20.00,21.00

-4.00,20.00,21.00

-4.00,20.00,21.00

-4.00,20.00,21.00

-4.00,20.00,21.00

-2.00,18.00,33.00

-2.00,18.00,33.00

-2.00,18.00,33.00

-2.00,18.00,33.00

-2.00,18.00,33.00

-2.00,18.00,33.00

-2.00,18.00,33.00

0.00,19.00,27.00

0.00,19.00,27.00

0.00,19.00,27.00

0.00,19.00,27.00

0.00,19.00,27.00

0.00,19.00,27.00

0.00,19.00,27.00

0.00,19.00,27.00

0.00,22.00,27.00

0.00,22.00,27.00

0.00,22.00,27.00

0.00,22.00,27.00

0.00,22.00,27.00

0.00,22.00,27.00

0.00,22.00,27.00

0.00,22.00,27.00

0.00,19.00,32.00

0.00,19.00,32.00

0.00,19.00,32.00

0.00,19.00,32.00

0.00,19.00,32.00

0.00,19.00,32.00

0.00,19.00,32.00

1.00,20.00,33.00

1.00,20.00,33.00

1.00,20.00,33.00

1.00,20.00,33.00

1.00,20.00,33.00

1.00,20.00,33.00

1.00,20.00,33.00

1.00,20.00,33.00

1.00,27.00,29.00

1.00,27.00,29.00

1.00,27.00,29.00

1.00,27.00,29.00

1.00,27.00,29.00

1.00,27.00,29.00

1.00,27.00,29.00

1.00,29.00,29.00

1.00,29.00,29.00

1.00,29.00,29.00

1.00,29.00,29.00

1.00,29.00,29.00

1.00,29.00,29.00

1.00,29.00,29.00

1.00,29.00,29.00

-1.00,33.00,32.00

-1.00,33.00,32.00

-1.00,33.00,32.00

-1.00,33.00,32.00

-1.00,33.00,32.00

-1.00,33.00,32.00

-1.00,33.00,32.00

-2.00,33.00,31.00

-2.00,33.00,31.00

-2.00,33.00,31.00

-2.00,33.00,31.00

-2.00,33.00,31.00

-2.00,33.00,31.00

-2.00,33.00,31.00

-2.00,33.00,31.00

-5.00,38.00,33.00

-5.00,38.00,33.00

-5.00,38.00,33.00

-5.00,38.00,33.00

-5.00,38.00,33.00

-5.00,38.00,33.00

-5.00,38.00,33.00

-8.00,35.00,39.00

-8.00,35.00,39.00

-8.00,35.00,39.00

-8.00,35.00,39.00

-8.00,35.00,39.00

-8.00,35.00,39.00

-8.00,35.00,39.00

-7.00,37.00,41.00

-7.00,37.00,41.00

-7.00,37.00,41.00

-7.00,37.00,41.00

-7.00,37.00,41.00

-7.00,37.00,41.00

-7.00,37.00,41.00

-7.00,37.00,41.00

-9.00,35.00,39.00

-9.00,35.00,39.00

-9.00,35.00,39.00

-9.00,35.00,39.00

-9.00,35.00,39.00

-9.00,35.00,39.00

-9.00,35.00,39.00

-11.00,30.00,41.00

-11.00,30.00,41.00

-11.00,30.00,41.00

-11.00,30.00,41.00

-11.00,30.00,41.00

-11.00,30.00,41.00

-11.00,30.00,41.00

-11.00,30.00,41.00

-14.00,33.00,48.00

-14.00,33.00,48.00

-14.00,33.00,48.00

-14.00,33.00,48.00

-14.00,33.00,48.00

-14.00,33.00,48.00

-14.00,33.00,48.00

-14.00,33.00,48.00

-22.00,25.00,50.00

-22.00,25.00,50.00

-22.00,25.00,50.00

-22.00,25.00,50.00

-22.00,25.00,50.00

-22.00,25.00,50.00

-22.00,25.00,50.00

-21.00,24.00,48.00

-21.00,24.00,48.00

-21.00,24.00,48.00

-21.00,24.00,48.00

-21.00,24.00,48.00

-21.00,24.00,48.00

-21.00,24.00,48.00

-21.00,24.00,48.00

-20.00,24.00,51.00

-20.00,24.00,51.00

-20.00,24.00,51.00

-20.00,24.00,51.00

-20.00,24.00,51.00

-20.00,24.00,51.00

-20.00,24.00,51.00

-22.00,24.00,54.00

-22.00,24.00,54.00

-22.00,24.00,54.00

-22.00,24.00,54.00

-22.00,24.00,54.00

-22.00,24.00,54.00

-22.00,24.00,54.00

-22.00,24.00,54.00

-22.00,23.00,46.00

-22.00,23.00,46.00

-22.00,23.00,46.00

-22.00,23.00,46.00

-22.00,23.00,46.00

-22.00,23.00,46.00

-22.00,23.00,46.00

-20.00,24.00,49.00

-20.00,24.00,49.00

-20.00,24.00,49.00

-20.00,24.00,49.00

-20.00,24.00,49.00

-20.00,24.00,49.00

-20.00,24.00,49.00

-20.00,24.00,49.00

-24.00,19.00,53.00

-24.00,19.00,53.00

-24.00,19.00,53.00

-24.00,19.00,53.00

-24.00,19.00,53.00

-24.00,19.00,53.00

-24.00,19.00,53.00

-24.00,19.00,53.00

-24.00,16.00,53.00

-24.00,16.00,53.00

-24.00,16.00,53.00

-24.00,16.00,53.00

-24.00,16.00,53.00

-24.00,16.00,53.00

-24.00,16.00,53.00

-24.00,12.00,47.00

-24.00,12.00,47.00

-24.00,12.00,47.00

-24.00,12.00,47.00

-24.00,12.00,47.00

-24.00,12.00,47.00

-24.00,12.00,47.00

-27.00,9.00,52.00

-27.00,9.00,52.00

-27.00,9.00,52.00

-27.00,9.00,52.00

-27.00,9.00,52.00

-27.00,9.00,52.00

-27.00,9.00,52.00

-27.00,9.00,52.00

-27.00,9.00,52.00

-23.00,10.00,53.00

-23.00,10.00,53.00

-23.00,10.00,53.00

-23.00,10.00,53.00

-23.00,10.00,53.00

-23.00,10.00,53.00

-23.00,10.00,53.00

-22.00,9.00,48.00

-22.00,9.00,48.00

-22.00,9.00,48.00

-22.00,9.00,48.00

-22.00,9.00,48.00

-22.00,9.00,48.00

-22.00,9.00,48.00

-22.00,9.00,48.00

-22.00,4.00,54.00

-22.00,4.00,54.00

-22.00,4.00,54.00

-22.00,4.00,54.00

-22.00,4.00,54.00

-22.00,4.00,54.00

-22.00,4.00,54.00

-19.00,3.00,54.00

-19.00,3.00,54.00

-19.00,3.00,54.00

-19.00,3.00,54.00

-19.00,3.00,54.00

-19.00,3.00,54.00

-19.00,3.00,54.00

-19.00,3.00,54.00

-17.00,2.00,50.00

-17.00,2.00,50.00

-17.00,2.00,50.00

-17.00,2.00,50.00

-17.00,2.00,50.00

-17.00,2.00,50.00

-17.00,2.00,50.00

-17.00,1.00,50.00

-17.00,1.00,50.00

-17.00,1.00,50.00

-17.00,1.00,50.00

-17.00,1.00,50.00

-17.00,1.00,50.00

-17.00,1.00,50.00

-17.00,1.00,55.00

-17.00,1.00,55.00

-17.00,1.00,55.00

-17.00,1.00,55.00

-17.00,1.00,55.00

-17.00,1.00,55.00

-17.00,1.00,55.00

-17.00,1.00,55.00

-16.00,3.00,50.00

-16.00,3.00,50.00

-16.00,3.00,50.00

-16.00,3.00,50.00

-16.00,3.00,50.00

-16.00,3.00,50.00

-16.00,3.00,50.00

-14.00,0.00,49.00

-14.00,0.00,49.00

-14.00,0.00,49.00

-14.00,0.00,49.00

-14.00,0.00,49.00

-14.00,0.00,49.00

-14.00,0.00,49.00

-14.00,0.00,49.00

-13.00,2.00,53.00

-13.00,2.00,53.00

-13.00,2.00,53.00

-13.00,2.00,53.00

-13.00,2.00,53.00

-13.00,2.00,53.00

-13.00,2.00,53.00

-14.00,3.00,50.00

-14.00,3.00,50.00

-14.00,3.00,50.00

-14.00,3.00,50.00

-14.00,3.00,50.00

-14.00,3.00,50.00

-14.00,3.00,50.00

-14.00,3.00,50.00

-13.00,2.00,53.00

-13.00,2.00,53.00

-13.00,2.00,53.00

-13.00,2.00,53.00

-13.00,2.00,53.00

-13.00,2.00,53.00

-13.00,2.00,53.00

-12.00,2.00,56.00

-12.00,2.00,56.00

-12.00,2.00,56.00

-12.00,2.00,56.00

-12.00,2.00,56.00

-12.00,2.00,56.00

-12.00,2.00,56.00

-12.00,2.00,56.00

-12.00,3.00,53.00

-12.00,3.00,53.00

-12.00,3.00,53.00

-12.00,3.00,53.00

-12.00,3.00,53.00

-12.00,3.00,53.00

-12.00,3.00,53.00

-10.00,-1.00,52.00

-10.00,-1.00,52.00

-10.00,-1.00,52.00

-10.00,-1.00,52.00

-10.00,-1.00,52.00

-10.00,-1.00,52.00

-10.00,-1.00,52.00

-10.00,0.00,49.00

-10.00,0.00,49.00

-10.00,0.00,49.00

-10.00,0.00,49.00

-10.00,0.00,49.00

-10.00,0.00,49.00

-10.00,0.00,49.00

-10.00,0.00,49.00

-11.00,1.00,53.00

-11.00,1.00,53.00

-11.00,1.00,53.00

-11.00,1.00,53.00

-11.00,1.00,53.00

-11.00,1.00,53.00

-11.00,1.00,53.00

-8.00,4.00,55.00

-8.00,4.00,55.00

-8.00,4.00,55.00

-8.00,4.00,55.00

-8.00,4.00,55.00

-8.00,4.00,55.00

-8.00,4.00,55.00

-8.00,4.00,55.00

-8.00,4.00,55.00

-8.00,4.00,54.00

-8.00,4.00,54.00

-8.00,4.00,54.00

-8.00,4.00,54.00

-8.00,4.00,54.00

-8.00,4.00,54.00

-8.00,4.00,54.00

-8.00,4.00,57.00

-8.00,4.00,57.00

-8.00,4.00,57.00

-8.00,4.00,57.00

-8.00,4.00,57.00

-8.00,4.00,57.00

-8.00,4.00,57.00

-8.00,4.00,57.00

-7.00,5.00,53.00

-7.00,5.00,53.00

-7.00,5.00,53.00

-7.00,5.00,53.00

-7.00,5.00,53.00

-7.00,5.00,53.00

-7.00,5.00,53.00

-5.00,3.00,58.00

-5.00,3.00,58.00

-5.00,3.00,58.00

-5.00,3.00,58.00

-5.00,3.00,58.00

-5.00,3.00,58.00

-5.00,3.00,58.00

-5.00,3.00,58.00

-6.00,7.00,54.00

-6.00,7.00,54.00

-6.00,7.00,54.00

-6.00,7.00,54.00

-6.00,7.00,54.00

-6.00,7.00,54.00

-6.00,7.00,54.00

-5.00,4.00,56.00

-5.00,4.00,56.00

-5.00,4.00,56.00

-5.00,4.00,56.00

-5.00,4.00,56.00

-5.00,4.00,56.00

-5.00,4.00,56.00

-5.00,4.00,56.00

-5.00,5.00,53.00

-5.00,5.00,53.00

-5.00,5.00,53.00

-5.00,5.00,53.00

-5.00,5.00,53.00

-5.00,5.00,53.00

-5.00,5.00,53.00

-4.00,3.00,57.00

-4.00,3.00,57.00

-4.00,3.00,57.00

-4.00,3.00,57.00

-4.00,3.00,57.00

-4.00,3.00,57.00

-4.00,3.00,57.00

-4.00,3.00,57.00

-4.00,3.00,54.00

-4.00,3.00,54.00

-4.00,3.00,54.00

-4.00,3.00,54.00

-4.00,3.00,54.00

-4.00,3.00,54.00

-4.00,3.00,54.00

-6.00,4.00,53.00

-6.00,4.00,53.00

-6.00,4.00,53.00

-6.00,4.00,53.00

-6.00,4.00,53.00

-6.00,4.00,53.00

-6.00,4.00,53.00

-7.00,5.00,53.00

-7.00,5.00,53.00

-7.00,5.00,53.00

-7.00,5.00,53.00

-7.00,5.00,53.00

-7.00,5.00,53.00

-7.00,5.00,53.00

-7.00,5.00,53.00

-8.00,2.00,56.00

-8.00,2.00,56.00

-8.00,2.00,56.00

-8.00,2.00,56.00

-8.00,2.00,56.00

-8.00,2.00,56.00

-8.00,2.00,56.00

-9.00,2.00,57.00

-9.00,2.00,57.00

-9.00,2.00,57.00

-9.00,2.00,57.00

-9.00,2.00,57.00

-9.00,2.00,57.00

-9.00,2.00,57.00

-9.00,2.00,57.00

-9.00,5.00,52.00

-9.00,5.00,52.00

-9.00,5.00,52.00

-9.00,5.00,52.00

-9.00,5.00,52.00

-9.00,5.00,52.00

-9.00,5.00,52.00

-12.00,2.00,55.00

-12.00,2.00,55.00

-12.00,2.00,55.00

-12.00,2.00,55.00

-12.00,2.00,55.00

-12.00,2.00,55.00

-12.00,2.00,55.00

-12.00,2.00,55.00

-12.00,1.00,53.00

-12.00,1.00,53.00

-12.00,1.00,53.00

-12.00,1.00,53.00

-12.00,1.00,53.00

-12.00,1.00,53.00

-12.00,1.00,53.00

-12.00,1.00,53.00

-12.00,1.00,52.00

-12.00,1.00,52.00

-12.00,1.00,52.00

-12.00,1.00,52.00

-12.00,1.00,52.00

-12.00,1.00,52.00

-12.00,1.00,52.00

-12.00,1.00,52.00

-13.00,1.00,54.00

-13.00,1.00,54.00

-13.00,1.00,54.00

-13.00,1.00,54.00

-13.00,1.00,54.00

-13.00,1.00,54.00

-13.00,1.00,54.00

-12.00,4.00,52.00

-12.00,4.00,52.00

-12.00,4.00,52.00

-12.00,4.00,52.00

-12.00,4.00,52.00

-12.00,4.00,52.00

-12.00,4.00,52.00

-12.00,4.00,52.00

-14.00,2.00,52.00

-14.00,2.00,52.00

-14.00,2.00,52.00

-14.00,2.00,52.00

-14.00,2.00,52.00

-14.00,2.00,52.00

-14.00,2.00,52.00

-14.00,4.00,53.00

-14.00,4.00,53.00

-14.00,4.00,53.00

-14.00,4.00,53.00

-14.00,4.00,53.00

-14.00,4.00,53.00

-14.00,4.00,53.00

-14.00,4.00,53.00

-14.00,3.00,57.00

-14.00,3.00,57.00

-14.00,3.00,57.00

-14.00,3.00,57.00

-14.00,3.00,57.00

-14.00,3.00,57.00

-14.00,3.00,57.00

-15.00,1.00,52.00

-15.00,1.00,52.00

-15.00,1.00,52.00

-15.00,1.00,52.00

-15.00,1.00,52.00

-15.00,1.00,52.00

-15.00,1.00,52.00

-15.00,1.00,52.00

-17.00,3.00,51.00

-17.00,3.00,51.00

-17.00,3.00,51.00

-17.00,3.00,51.00

-17.00,3.00,51.00

-17.00,3.00,51.00

-17.00,3.00,51.00

-17.00,5.00,49.00

-17.00,5.00,49.00

-17.00,5.00,49.00

-17.00,5.00,49.00

-17.00,5.00,49.00

-17.00,5.00,49.00

-17.00,5.00,49.00

-19.00,5.00,53.00

-19.00,5.00,53.00

-19.00,5.00,53.00

-19.00,5.00,53.00

-19.00,5.00,53.00

-19.00,5.00,53.00

-19.00,5.00,53.00

-19.00,5.00,53.00

-20.00,5.00,52.00

-20.00,5.00,52.00

-20.00,5.00,52.00

-20.00,5.00,52.00

-20.00,5.00,52.00

-20.00,5.00,52.00

-20.00,5.00,52.00

-19.00,3.00,55.00

-19.00,3.00,55.00

-19.00,3.00,55.00

-19.00,3.00,55.00

-19.00,3.00,55.00

-19.00,3.00,55.00

-19.00,3.00,55.00

-19.00,3.00,55.00

-20.00,6.00,52.00

-20.00,6.00,52.00

-20.00,6.00,52.00

-20.00,6.00,52.00

-20.00,6.00,52.00

-20.00,6.00,52.00

-20.00,6.00,52.00

-20.00,6.00,52.00

-24.00,5.00,51.00

-24.00,5.00,51.00

-24.00,5.00,51.00

-24.00,5.00,51.00

-24.00,5.00,51.00

-24.00,5.00,51.00

-24.00,5.00,51.00

-24.00,5.00,51.00

-25.00,10.00,52.00

-25.00,10.00,52.00

-25.00,10.00,52.00

-25.00,10.00,52.00

-25.00,10.00,52.00

-25.00,10.00,52.00

-25.00,10.00,52.00

-25.00,10.00,52.00

-26.00,12.00,50.00

-26.00,12.00,50.00

-26.00,12.00,50.00

-26.00,12.00,50.00

-26.00,12.00,50.00

-26.00,12.00,50.00

-26.00,12.00,50.00

-25.00,12.00,50.00

-25.00,12.00,50.00

-25.00,12.00,50.00

-25.00,12.00,50.00

-25.00,12.00,50.00

-25.00,12.00,50.00

-25.00,12.00,50.00

-25.00,12.00,50.00

-24.00,11.00,50.00

-24.00,11.00,50.00

-24.00,11.00,50.00

-24.00,11.00,50.00

-24.00,11.00,50.00

-24.00,11.00,50.00

-24.00,11.00,50.00

-25.00,12.00,52.00

-25.00,12.00,52.00

-25.00,12.00,52.00

-25.00,12.00,52.00

-25.00,12.00,52.00

-25.00,12.00,52.00

-25.00,12.00,52.00

-25.00,15.00,52.00

-25.00,15.00,52.00

-25.00,15.00,52.00

-25.00,15.00,52.00

-25.00,15.00,52.00

-25.00,15.00,52.00

-25.00,15.00,52.00

-25.00,15.00,52.00

-26.00,12.00,51.00

-26.00,12.00,51.00

-26.00,12.00,51.00

-26.00,12.00,51.00

-26.00,12.00,51.00

-26.00,12.00,51.00

-26.00,12.00,51.00

-24.00,12.00,53.00

-24.00,12.00,53.00

-24.00,12.00,53.00

-24.00,12.00,53.00

-24.00,12.00,53.00

-24.00,12.00,53.00

-24.00,12.00,53.00

-24.00,12.00,53.00

-25.00,16.00,48.00

-25.00,16.00,48.00

-25.00,16.00,48.00

-25.00,16.00,48.00

-25.00,16.00,48.00

-25.00,16.00,48.00

-25.00,16.00,48.00

-26.00,14.00,55.00

-26.00,14.00,55.00

-26.00,14.00,55.00

-26.00,14.00,55.00

-26.00,14.00,55.00

-26.00,14.00,55.00

-26.00,14.00,55.00

-26.00,14.00,55.00

-26.00,16.00,52.00

-26.00,16.00,52.00

-26.00,16.00,52.00

-26.00,16.00,52.00

-26.00,16.00,52.00

-26.00,16.00,52.00

-26.00,16.00,52.00

-26.00,21.00,50.00

-26.00,21.00,50.00

-26.00,21.00,50.00

-26.00,21.00,50.00

-26.00,21.00,50.00

-26.00,21.00,50.00

-26.00,21.00,50.00

-26.00,21.00,50.00

-18.00,22.00,53.00

-18.00,22.00,53.00

-18.00,22.00,53.00

-18.00,22.00,53.00

-18.00,22.00,53.00

-18.00,22.00,53.00

-18.00,22.00,53.00

-18.00,22.00,53.00

-17.00,23.00,45.00

-17.00,23.00,45.00

-17.00,23.00,45.00

-17.00,23.00,45.00

-17.00,23.00,45.00

-17.00,23.00,45.00

-17.00,23.00,45.00

-17.00,23.00,45.00

-17.00,23.00,50.00

-17.00,23.00,50.00

-17.00,23.00,50.00

-17.00,23.00,50.00

-17.00,23.00,50.00

-17.00,23.00,50.00

-17.00,23.00,50.00

-17.00,23.00,50.00

-9.00,23.00,45.00

-9.00,23.00,45.00

-9.00,23.00,45.00

-9.00,23.00,45.00

-9.00,23.00,45.00

-9.00,23.00,45.00

-9.00,23.00,45.00

-9.00,23.00,45.00

-5.00,22.00,38.00

-5.00,22.00,38.00

-5.00,22.00,38.00

-5.00,22.00,38.00

-5.00,22.00,38.00

-5.00,22.00,38.00

-5.00,22.00,38.00

-8.00,17.00,35.00

-8.00,17.00,35.00

-8.00,17.00,35.00

-8.00,17.00,35.00

-8.00,17.00,35.00

-8.00,17.00,35.00

-8.00,17.00,35.00

-8.00,15.00,32.00

-8.00,15.00,32.00

-8.00,15.00,32.00

-8.00,15.00,32.00

-8.00,15.00,32.00

-8.00,15.00,32.00

-8.00,15.00,32.00

-8.00,15.00,32.00

-14.00,12.00,29.00

-14.00,12.00,29.00

-14.00,12.00,29.00

-14.00,12.00,29.00

-14.00,12.00,29.00

-14.00,12.00,29.00

-14.00,12.00,29.00

-20.00,10.00,30.00

-20.00,10.00,30.00

-20.00,10.00,30.00

-20.00,10.00,30.00

-20.00,10.00,30.00

-20.00,10.00,30.00

-20.00,10.00,30.00

-20.00,10.00,30.00

-20.00,10.00,35.00

-20.00,10.00,35.00

-20.00,10.00,35.00

-20.00,10.00,35.00

-20.00,10.00,35.00

-20.00,10.00,35.00

-20.00,10.00,35.00

-21.00,14.00,35.00

-21.00,14.00,35.00

-21.00,14.00,35.00

-21.00,14.00,35.00

-21.00,14.00,35.00

-21.00,14.00,35.00

-21.00,14.00,35.00

-21.00,14.00,35.00

-20.00,15.00,40.00

-20.00,15.00,40.00

-20.00,15.00,40.00

-20.00,15.00,40.00

-20.00,15.00,40.00

-20.00,15.00,40.00

-20.00,15.00,40.00

-22.00,21.00,43.00

-22.00,21.00,43.00

-22.00,21.00,43.00

-22.00,21.00,43.00

-22.00,21.00,43.00

-22.00,21.00,43.00

-22.00,21.00,43.00

-22.00,21.00,43.00

-16.00,25.00,50.00

-16.00,25.00,50.00

-16.00,25.00,50.00

-16.00,25.00,50.00

-16.00,25.00,50.00

-16.00,25.00,50.00

-16.00,25.00,50.00

-15.00,27.00,52.00

-15.00,27.00,52.00

-15.00,27.00,52.00

-15.00,27.00,52.00

-15.00,27.00,52.00

-15.00,27.00,52.00

-15.00,27.00,52.00

-15.00,27.00,52.00

-14.00,24.00,50.00

-14.00,24.00,50.00

-14.00,24.00,50.00

-14.00,24.00,50.00

-14.00,24.00,50.00

-14.00,24.00,50.00

-14.00,24.00,50.00

-13.00,28.00,50.00

-13.00,28.00,50.00

-13.00,28.00,50.00

-13.00,28.00,50.00

-13.00,28.00,50.00

-13.00,28.00,50.00

-13.00,28.00,50.00

-11.00,26.00,48.00

-11.00,26.00,48.00

-11.00,26.00,48.00

-11.00,26.00,48.00

-11.00,26.00,48.00

-11.00,26.00,48.00

-11.00,26.00,48.00

-11.00,26.00,48.00

-10.00,28.00,52.00

-10.00,28.00,52.00

-10.00,28.00,52.00

-10.00,28.00,52.00

-10.00,28.00,52.00

-10.00,28.00,52.00

-10.00,28.00,52.00

-9.00,26.00,54.00

-9.00,26.00,54.00

-9.00,26.00,54.00

-9.00,26.00,54.00

-9.00,26.00,54.00

-9.00,26.00,54.00

-9.00,26.00,54.00

-9.00,26.00,54.00

-7.00,27.00,56.00

-7.00,27.00,56.00

-7.00,27.00,56.00

-7.00,27.00,56.00

-7.00,27.00,56.00

-7.00,27.00,56.00

-7.00,27.00,56.00

-7.00,26.00,56.00

-7.00,26.00,56.00

-7.00,26.00,56.00

-7.00,26.00,56.00

-7.00,26.00,56.00

-7.00,26.00,56.00

-7.00,26.00,56.00

-7.00,26.00,56.00

-4.00,23.00,56.00

-4.00,23.00,56.00

-4.00,23.00,56.00

-4.00,23.00,56.00

-4.00,23.00,56.00

-4.00,23.00,56.00

-4.00,23.00,56.00

-4.00,23.00,56.00

-3.00,25.00,59.00

-3.00,25.00,59.00

-3.00,25.00,59.00

-3.00,25.00,59.00

-3.00,25.00,59.00

-3.00,25.00,59.00

-3.00,25.00,59.00

-2.00,22.00,54.00

-2.00,22.00,54.00

-2.00,22.00,54.00

-2.00,22.00,54.00

-2.00,22.00,54.00

-2.00,22.00,54.00

-2.00,22.00,54.00

-2.00,22.00,54.00

-2.00,20.00,58.00

-2.00,20.00,58.00

-2.00,20.00,58.00

-2.00,20.00,58.00

-2.00,20.00,58.00

-2.00,20.00,58.00

-2.00,20.00,58.00

-1.00,20.00,54.00

-1.00,20.00,54.00

-1.00,20.00,54.00

-1.00,20.00,54.00

-1.00,20.00,54.00

-1.00,20.00,54.00

-1.00,20.00,54.00

-1.00,20.00,54.00

-1.00,21.00,59.00

-1.00,21.00,59.00

-1.00,21.00,59.00

-1.00,21.00,59.00

-1.00,21.00,59.00

-1.00,21.00,59.00

-1.00,21.00,59.00

-3.00,20.00,56.00

-3.00,20.00,56.00

-3.00,20.00,56.00

-3.00,20.00,56.00

-3.00,20.00,56.00

-3.00,20.00,56.00

-3.00,20.00,56.00

0.00,16.00,54.00

0.00,16.00,54.00

0.00,16.00,54.00

0.00,16.00,54.00

0.00,16.00,54.00

0.00,16.00,54.00

0.00,16.00,54.00

0.00,16.00,54.00

0.00,16.00,54.00

0.00,16.00,54.00

0.00,16.00,54.00

0.00,16.00,54.00

0.00,16.00,54.00

0.00,16.00,54.00

0.00,16.00,54.00

-1.00,12.00,56.00

-1.00,12.00,56.00

-1.00,12.00,56.00

-1.00,12.00,56.00

-1.00,12.00,56.00

-1.00,12.00,56.00

-1.00,12.00,56.00

-1.00,12.00,56.00

0.00,12.00,56.00

0.00,12.00,56.00

0.00,12.00,56.00

0.00,12.00,56.00

0.00,12.00,56.00

0.00,12.00,56.00

0.00,12.00,56.00

-3.00,12.00,51.00

-3.00,12.00,51.00

-3.00,12.00,51.00

-3.00,12.00,51.00

-3.00,12.00,51.00

-3.00,12.00,51.00

-3.00,12.00,51.00

-3.00,12.00,51.00

-2.00,13.00,54.00

-2.00,13.00,54.00

-2.00,13.00,54.00

-2.00,13.00,54.00

-2.00,13.00,54.00

-2.00,13.00,54.00

-2.00,13.00,54.00

-2.00,12.00,53.00

-2.00,12.00,53.00

-2.00,12.00,53.00

-2.00,12.00,53.00

-2.00,12.00,53.00

-2.00,12.00,53.00

-2.00,12.00,53.00

-2.00,12.00,53.00

-1.00,13.00,55.00

-1.00,13.00,55.00

-1.00,13.00,55.00

-1.00,13.00,55.00

-1.00,13.00,55.00

-1.00,13.00,55.00

-1.00,13.00,55.00

-1.00,14.00,56.00

-1.00,14.00,56.00

-1.00,14.00,56.00

-1.00,14.00,56.00

-1.00,14.00,56.00

-1.00,14.00,56.00

-1.00,14.00,56.00

1.00,12.00,55.00

1.00,12.00,55.00
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

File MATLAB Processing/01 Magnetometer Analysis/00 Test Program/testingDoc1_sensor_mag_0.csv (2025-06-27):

timestamp | timestamp_sample | device_id | x | y | z | temperature | error_count | is_external
8476665517 | 8476664396 | 4395041 | -0.28861383 | -0.14992926 | 0.32234278 | nan | 0 | 0
8476715515 | 8476714395 | 4395041 | -0.29235536 | -0.15742213 | 0.32229358 | nan | 0 | 0
8477665517 | 8477664396 | 4395041 | -0.28111094 | -0.15367398 | 0.30021867 | nan | 0 | 0
8478665515 | 8478664395 | 4395041 | -0.28485906 | -0.16866656 | 0.30463365 | nan | 0 | 0
8479665516 | 8479664395 | 4395041 | -0.29611027 | -0.15742573 | 0.32234278 | nan | 0 | 0
8480665515 | 8480664395 | 4395041 | -0.30360675 | -0.16117395 | 0.31792712 | nan | 0 | 0
8481665526 | 8481664405 | 4395041 | -0.3185851 | -0.16116656 | 0.31783015 | nan | 0 | 0
8482665516 | 8482664395 | 4395041 | -0.28111094 | -0.16117027 | 0.30904865 | nan | 0 | 0
8483665515 | 8483664394 | 4395041 | -0.28111735 | -0.16117395 | 0.31792712 | nan | 0 | 0
8484615515 | 8484614395 | 4395041 | -0.2886072 | -0.1649184 | 0.3178786 | nan | 0 | 0
8485665516 | 8485664395 | 4395041 | -0.2773628 | -0.15367398 | 0.32229358 | nan | 0 | 0
8486665515 | 8486664395 | 4395041 | -0.30734795 | -0.14617768 | 0.31346363 | nan | 0 | 0
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

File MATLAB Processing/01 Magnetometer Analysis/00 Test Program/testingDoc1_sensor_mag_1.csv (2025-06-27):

timestamp | timestamp_sample | device_id | x | y | z | temperature | error_count | is_external
8476757540 | 8476756594 | 396809 | 0.09166666 | 0.09318182 | 0.16136363 | nan | 0 | 1
8476779192 | 8476778246 | 396809 | 0.09469697 | 0.09166666 | 0.15984848 | nan | 0 | 1
8477760984 | 8477760037 | 396809 | 0.09469697 | 0.093939394 | 0.15454546 | nan | 0 | 1
8478764061 | 8478763115 | 396809 | 0.09166666 | 0.09015151 | 0.16666666 | nan | 0 | 1
8479745743 | 8479744797 | 396809 | 0.08863636 | 0.090909086 | 0.15833333 | nan | 0 | 1
8480749234 | 8480748288 | 396809 | 0.089393936 | 0.09166666 | 0.15454546 | nan | 0 | 1
8481752152 | 8481751206 | 396809 | 0.09318182 | 0.092424236 | 0.1651515 | nan | 0 | 1
8482755699 | 8482754753 | 396809 | 0.08863636 | 0.09015151 | 0.15833333 | nan | 0 | 1
8483758597 | 8483757651 | 396809 | 0.090909086 | 0.095454544 | 0.1560606 | nan | 0 | 1
8484761803 | 8484760857 | 396809 | 0.090909086 | 0.090909086 | 0.16363636 | nan | 0 | 1
8485743794 | 8485742837 | 396809 | 0.09015151 | 0.09166666 | 0.15833333 | nan | 0 | 1
8486747007 | 8486746061 | 396809 | 0.09318182 | 0.09015151 | 0.16666666 | nan | 0 | 1
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

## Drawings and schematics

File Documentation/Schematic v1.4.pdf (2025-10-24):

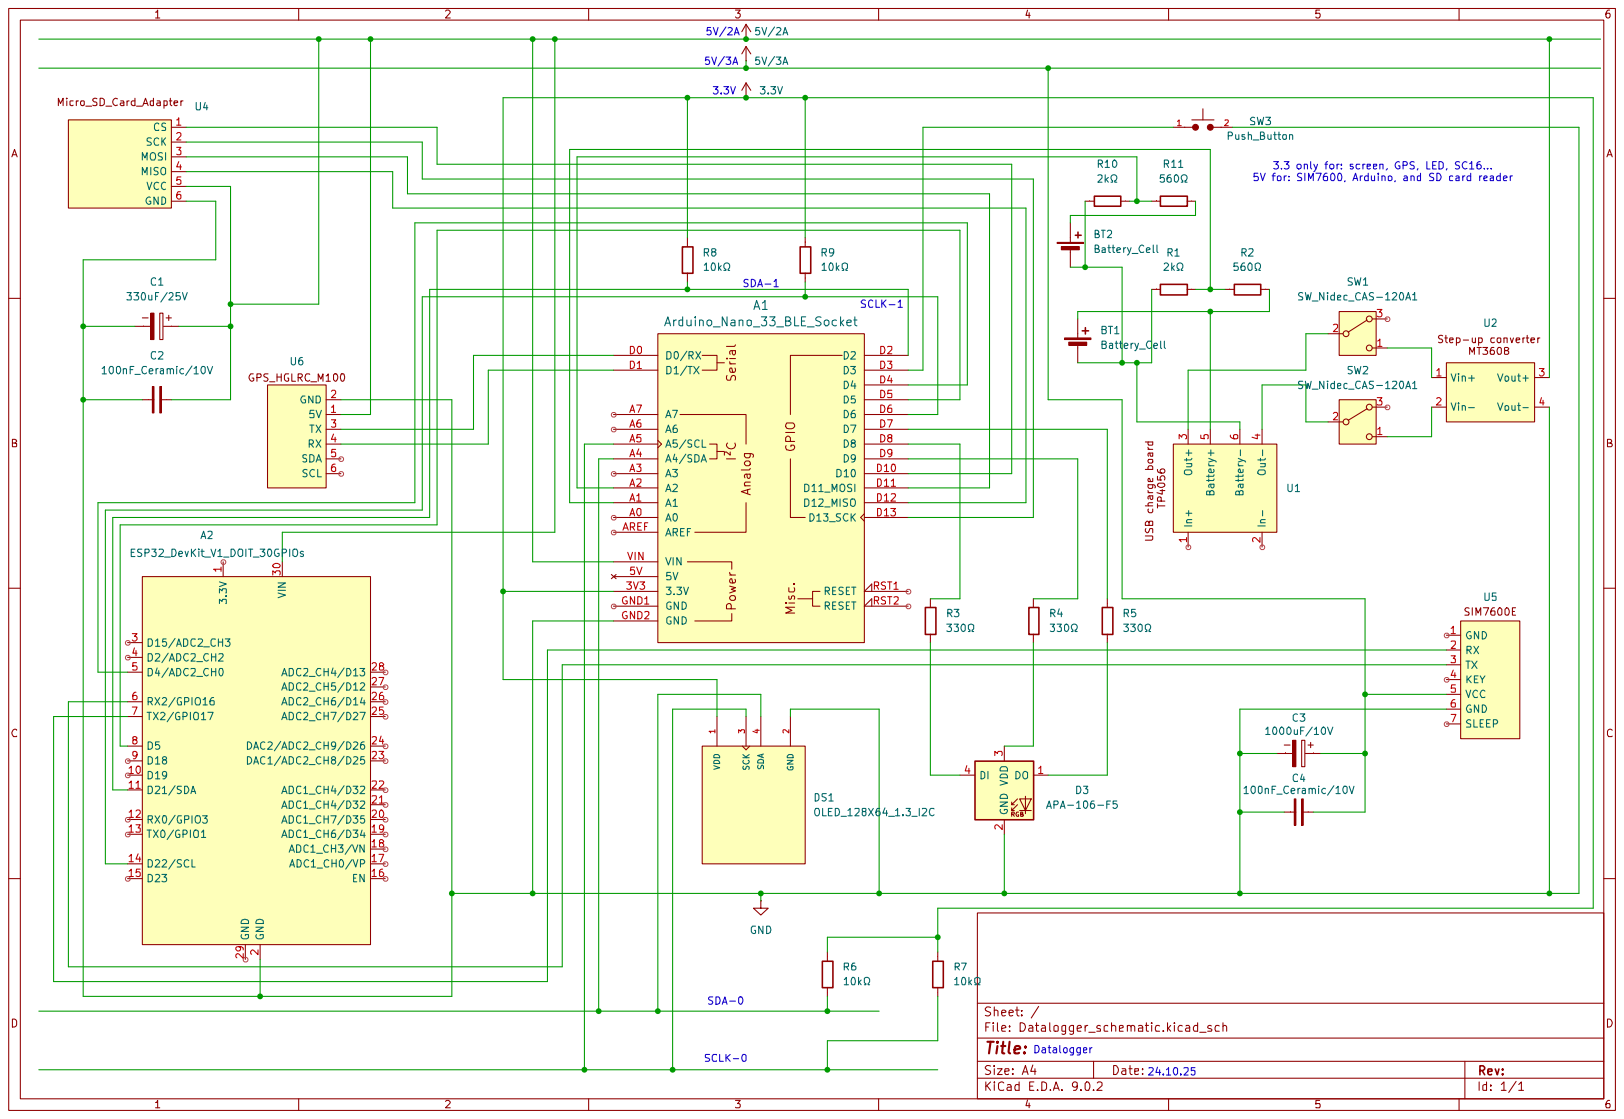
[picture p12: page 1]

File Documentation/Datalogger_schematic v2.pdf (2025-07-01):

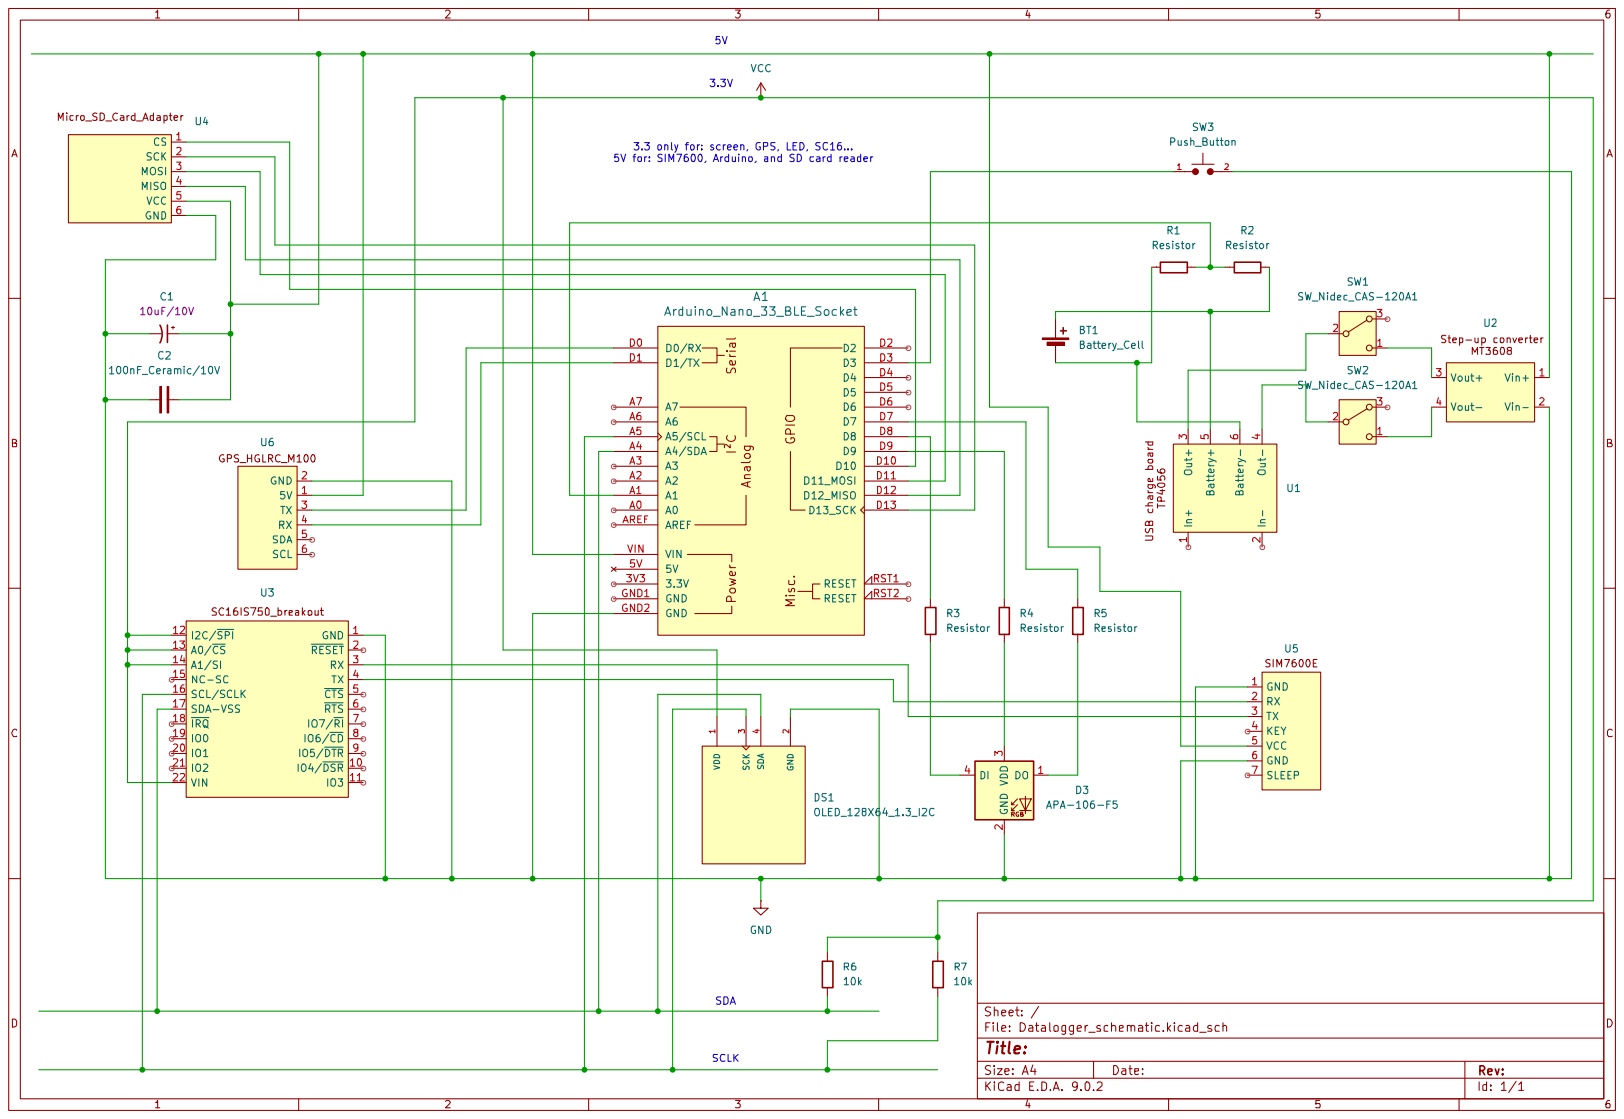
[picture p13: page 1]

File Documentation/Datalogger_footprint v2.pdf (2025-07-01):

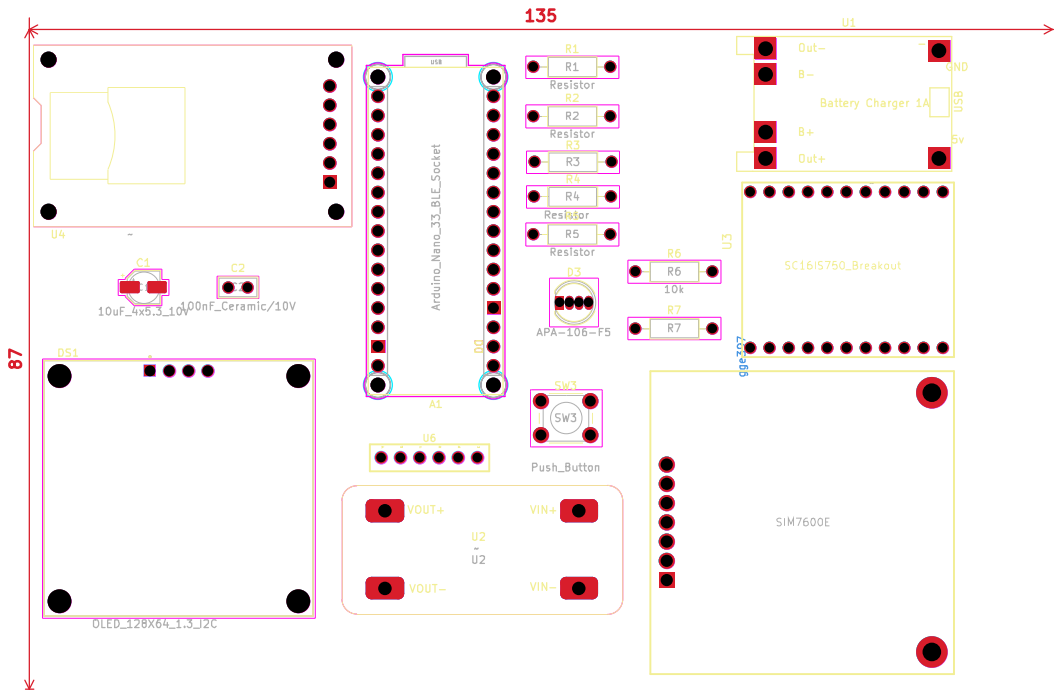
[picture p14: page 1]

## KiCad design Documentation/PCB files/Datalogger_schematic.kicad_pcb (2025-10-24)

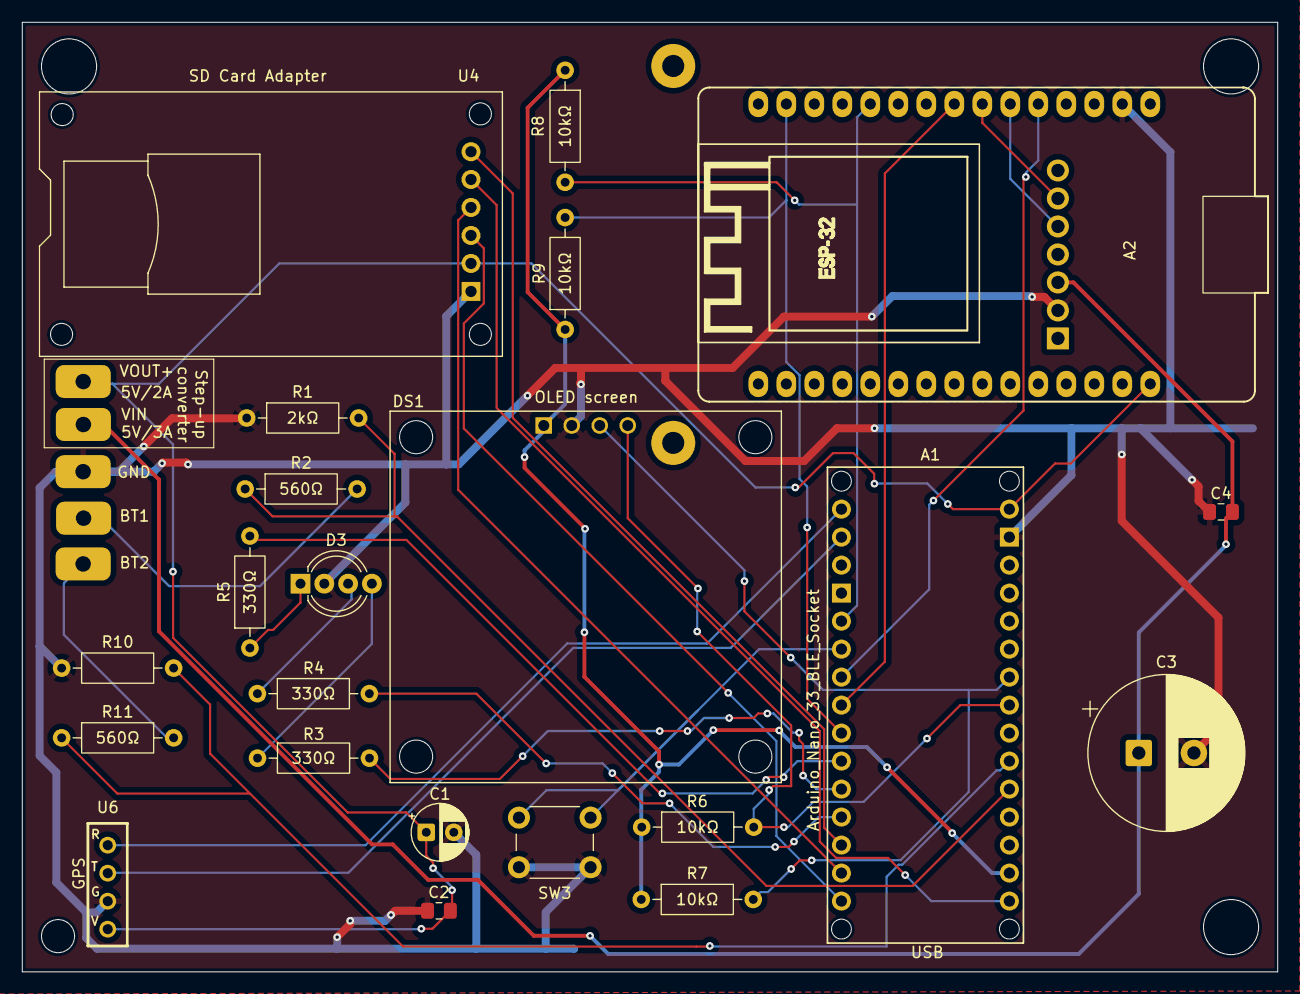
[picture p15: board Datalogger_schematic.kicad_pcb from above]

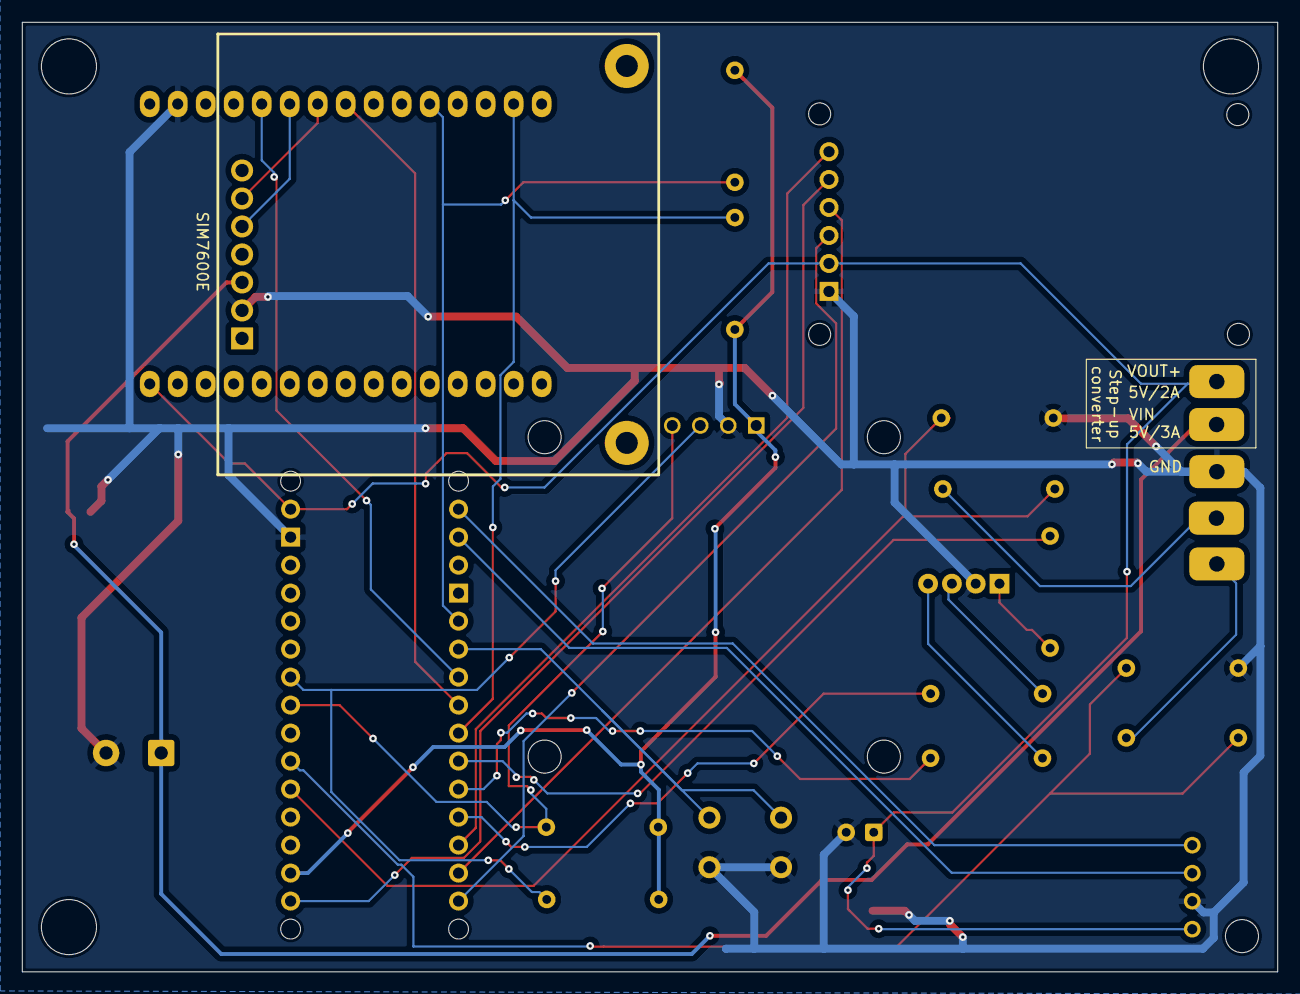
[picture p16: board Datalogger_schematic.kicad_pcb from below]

Board: 2 copper layers, 113.9 x 86.2 mm, 26 parts (2 on the bottom side), 29 nets.

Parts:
A1: Arduino_Nano_33_BLE_Socket; Arduino_Nano_Every_Socket
A2: ESP32_DevKit_V1_DOIT_30GPIOs; DOIT_ESP32_DEVKIT_30Pins
BT1, BT2: Battery_Cell; Battery single pin
C1: 330uF/10V; CP_Radial_D5.0mm_P2.50mm
C2, C4: 100nF_Ceramic/10V; C_0805_2012Metric_Pad1.18x1.45mm_HandSolder
C3: 1000uF/10V; CP_Radial_D14.0mm_P5.00mm
D3: APA-106-F5; LED_D5.0mm-4_RGB_Wide_Pins
DS1: OLED_128X64_1.3_I2C; LCD_OLED_128X64_1.3_I2C
R1, R2, R3, R4, R5, R10, R11: Resistor; R_Axial_DIN0207_L6.3mm_D2.5mm_P10.16mm_Horizontal
R6, R7, R8, R9: 10k; R_Axial_DIN0207_L6.3mm_D2.5mm_P10.16mm_Horizontal
SW3: Push_Button; SW_PUSH_6mm
U2: MT3608-Module
U4: Micro_SD_Card_Module
U5: SIM7600E
U6: GPS6PIN

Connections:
3.3V: A1.3V3 (3.3V), DS1.1 (VDD), R6.1, R7.1, R8.1, R9.1
5V/2A: A1.VIN, A2.30 (VIN), C1.1, C2.2, U2.3 (Vout+), U4.5 (VCC), U6.1 (5V)
5V/3A: C3.1, C4.2, U5.5 (VCC)
GND: A1.GND2 (GND), A2.2 (GND), C1.2, C2.1, C3.2, C4.1, D3.2 (GND), DS1.2 (GND), R1.1, R10.1, SW3.2, U4.6 (GND), U5.6 (GND), U6.2 (GND)
unnamed: A1.A4 (A4/SDA), DS1.4 (SDA), R6.2
unnamed: A1.A5 (A5/SCL), DS1.3 (SCK), R7.2
unnamed: A1.D0 (D0/RX), U6.3 (TX)
unnamed: A1.D1 (D1/TX), U6.4 (RX)
unnamed: A1.D11 (D11_MOSI), U4.3 (MOSI)
unnamed: A1.D12 (D12_MISO), U4.4 (MISO)
unnamed: A1.D13 (D13_SCK), U4.2 (SCK)
unnamed: A1.A1, R1.2, R2.1
unnamed: A1.A2, R10.2, R11.1
unnamed: A1.D3, SW3.1
unnamed: A1.D7, R5.2
unnamed: A1.D8, R3.2
unnamed: A1.D9, R4.2
unnamed: A1.D4, A2.5 (D4/ADC2_CH0)
unnamed: A1.D5, A2.8 (D5)
unnamed: A1.D2, A2.11 (D21/SDA), R8.2
unnamed: A1.D6, A2.14 (D22/SCL), R9.2
unnamed: A2.6 (RX2/GPIO16), U5.3 (TX)
unnamed: A2.7 (TX2/GPIO17), U5.2 (RX)
unnamed: BT1.1 (+), R2.2
unnamed: BT2.1 (+), R11.2
unnamed: D3.4 (DI), R3.1
unnamed: D3.1 (DO), R5.1
unnamed: D3.3 (VDD), R4.1
unnamed: A1.D10, U4.1 (CS)

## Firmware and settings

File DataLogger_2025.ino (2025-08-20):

#include <Arduino_BMI270_BMM150.h>  // Rev2 IMU
#include <SPI.h>
#include <SD.h>
#include <Wire.h>
#include <U8g2lib.h>
#include <Arduino_LPS22HB.h> // Barometric sensor (LPS22HB)
#include <TinyGPSPlus.h>
#include <Arduino.h>
#include <CircularBuffer.hpp>
#include "Kalman.h" // Source: https://github.com/TKJElectronics/KalmanFilter

// team number 
#define IDataLoggerId 1
#define MIN_SATS_REQUIRED 4
#define GPS_LOCK_TIMEOUT_MS 30000  // 30 seconds
#define loggingPeriod 100 // logging Period in milli seconds. Logging Freq= 1/ loggingPeriod KHz

// === ESP & SIM7600 constants ===
#define ESP32_ADDR 0x42
#define READY_LINE 4
#define ACK_LINE   5
#define LED_PIN    13
#define SDA_ESP    2
#define SCL_ESP    6
#define BUCKET_SIZE 5

// === Calibration constants ===
#define CALIB_SAFETY_CHECK 1    // boolean
#define CALIB_DEBUG 0
#define CALIB_MIN_ACCURACY 60   // Recommended: 60. Maximum: 90

TwoWire WireESP(SDA_ESP, SCL_ESP);  // Second I2C bus on Nano BLE Sense Rev2

// Create GPS parser
TinyGPSPlus gps;
//////////////////////////////////////////////
//        RemoteXY include library          //
//////////////////////////////////////////////

// you can enable debug logging to Serial at 115200
//#define REMOTEXY__DEBUGLOG    

// RemoteXY select connection mode and include library 
#define REMOTEXY_MODE__ARDUINOBLE

#include <ArduinoBLE.h>

// RemoteXY connection settings 
#define REMOTEXY_BLUETOOTH_NAME "Datalogger1"
#define REMOTEXY_ACCESS_PASSWORD "NFC123"


#include <RemoteXY.h>

// RemoteXY GUI configuration  
#pragma pack(push, 1)  
uint8_t RemoteXY_CONF[] =   // 242 bytes
  { 255,4,0,20,0,235,0,19,0,0,0,68,97,116,97,108,111,103,103,101,
  114,49,0,25,1,200,84,1,1,12,0,129,65,2,58,10,64,17,68,97,
  116,97,32,76,111,103,103,101,114,0,67,47,34,100,10,5,135,26,16,129,
  166,37,21,4,64,2,79,114,105,101,110,116,97,116,105,111,110,0,1,86,
  48,21,21,0,95,31,0,67,121,4,11,8,77,2,26,1,129,85,25,24,
  7,64,2,83,116,97,116,117,115,58,0,129,85,72,23,4,64,95,80,117,
  115,104,32,66,117,116,116,111,110,0,12,163,23,29,5,194,30,26,49,0,
  50,0,52,0,52,0,12,163,43,29,5,192,30,26,49,0,50,0,12,7,
  21,29,6,199,30,26,49,0,50,0,51,0,52,0,53,0,54,0,55,0,
  56,0,57,0,129,2,15,44,4,64,2,84,101,97,109,32,78,117,109,98,
  101,114,32,83,101,108,101,99,116,111,114,0,129,157,17,44,4,64,2,70,
  108,105,103,104,116,32,78,117,109,98,101,114,32,83,101,108,101,99,116,111,
  114,0 };
  
// this structure defines all the variables and events of your control interface 
struct {

    // input variables
  uint8_t PushButton; // =1 if button pressed, else =0
  uint8_t FlightNumber; // from 0 to 4
  uint8_t Orientation; // from 0 to 2
  uint8_t TeamNumber; // from 0 to 9

    // output variables
  char statusGui[16]; // string UTF8 end zero
  float DataLoggerId;

    // other variable
  uint8_t connect_flag;  // =1 if wire connected, else =0

} RemoteXY;   
#pragma pack(pop)
 
/////////////////////////////////////////////
//           END RemoteXY include          //
/////////////////////////////////////////////


//Global parameters from gui
int FLIGHT_NUMBER;
int TEAM_NUMBER;
int Orientation;

// Voltage divider values
const float R1 = 1786.0; // 1800Ohms 
const float R2 = 505.0;  // 510 Ohms

//=== Pin Assignment for batt indicators===
// constexpr tells the compiler that the value of a variabl can (and should) be evaluated at compile time
constexpr uint8_t PIN_LED_RED = 8; 
constexpr uint8_t PIN_LED_GREEN = 9; 
constexpr uint8_t PIN_LED_BLUE = 7; 
constexpr uint8_t PIN_BAT1_VSENSE = A1;
constexpr uint8_t PIN_BAT2_VSENSE = A2;

// === Battery Indicator Values ===
constexpr uint16_t ADC_MAX = 4095; // at 12-bit resolution
constexpr float VREF = 3.30F; // Volts 
constexpr float BAT_VLOW = 3.50F; // Volts at low battery
float battery1Voltage = 0;
float battery2Voltage = 0;


// === OLED Setup (SH1106 I2C) ===
U8G2_SH1106_128X64_NONAME_F_HW_I2C u8g2(U8G2_R0, /* reset=*/ U8X8_PIN_NONE);

// === SD Card Config ===
const int chipSelect = 10;
File dataFile;
char filename[13];  // 8 + 1 + 3 + null terminator = 13 -- arduino lib deals with 8.3 format! 8 letetrs and . then 3 letter as extention 


// === Global Sensor Variables ===
unsigned long timestamp;
float accX, accY, accZ;
float gyroX, gyroY, gyroZ;
float magX, magY, magZ;
float latitude, longitude, gpsAltitude, Speed = 0.0;  //&speed in km/h
int SatCount = 0; 
float pressure, paltitude, temperature; 

// === Attitude Angle Variables ===
bool firstIteration = true;
Kalman kalmanX, kalmanY, kalmanZ;
float roll = 0, pitch = 0, yaw = 0;
double rollFinal, pitchFinal, yawFinal; // Calculated angle using a Kalman filter
double gyroXangle, gyroYangle, gyroZangle; // Angle calculate using the gyro only
double gyroXrate, gyroYrate, gyroZrate;
double dt;
unsigned long timer = 0;

// === Display Variables ===
unsigned long lastDisplaySwitch = 0; // Keep track of the last time the display was updated
int displayState = 0;                // Keep track of what to show: 0 = team, 1 = battery, 2 = satellites

// === Button Handling ===
const int PIN_BUTTON = 3;                // Make sure this is an interrupt-capable pin
constexpr uint8_t DEBOUNCE_MS = 200;

volatile bool buttonInterruptFlag = false;
unsigned long lastEdge = 0;
bool lastStableState = HIGH;            // Assuming pull-up resistor


//logging variables: 
// Logging state using enum
enum class LogState { IDLE, ACTIVE };
LogState logState = LogState::IDLE;

unsigned long lastWriteTime = 0;
unsigned long lastFlushTime = 0;
const unsigned long WRITE_INTERVAL = 1000;  // Write to SD every 1 sec
const unsigned long FLUSH_INTERVAL = 10000;  // Flush SD every 5 sec
String dataBuffer = ""; // Buffer for batching data

// ====== Calibration Variables ======
float accX_off  = 0, accY_off  = 0, accZ_off  = 0;
float gyroX_off = 0, gyroY_off = 0, gyroZ_off = 0;
float magX_off  = 0, magY_off  = 0, magZ_off  = 0;
float preAccX, preAccY, preAccZ = 0;
float preGyroX, preGyroY, preGyroZ = 0;
float preMagX, preMagY, preMagZ;
bool retryCalibration = 0;

// ====== Mode and Buffer Settings FOR ESP Sending ======
enum Mode { REALTIME, BATCH };
Mode currentMode = REALTIME;  // default mode

CircularBuffer<String, BUCKET_SIZE> sensorBuffer;

volatile bool espReady = false;
volatile bool I2CError = false;
bool awaitingAck = false;

//  ====== logging parameters ======
unsigned long now = 0;
unsigned long lastCollectTime = 0; 
unsigned long  LastI2CError = 0;

// === Function Declarations ===
void displayToScreen(const char str[], u8g2_uint_t x, u8g2_uint_t y);
void displayTwoLines(const char line1[], const char line2[], const uint8_t* font, u8g2_uint_t x1, u8g2_uint_t x2);
void updateIMUData();
void updateBarometerData();
String generateDataLine();
void logToSD();
void calibrateIMU(); 
void calibrateIMU2();
bool fullSpanCalibration(int16_t, int16_t, int16_t, int16_t, int16_t, int16_t);
void printIMUOffsetsAndReadings();
void attitudeInitialization();
void attitudeAngles();
void generateFilename(); 
void readNextLineFromSD();

// button logic, voltage divider, logging!
void onButtonPress();
bool buttonReleased();
void waitForButtonPressed();
void updateBatteryVoltage();
void checkBattery();
void startLog();
void stopLog();
void updateLogging(); // starts logging at button *release*
String buildJsonPayload(const String& jsonWrappedLine);
template <size_t N>
String buildJsonPayload(const CircularBuffer<String, N>& buffer);
void logToServer();
void log();
void waitForGPSLock(); 
void updateGPSData();
void onESPReady();


void setup() {
  Serial.begin(9600);    // USB serial for debug
  RemoteXY_Init (); 

  // Battery indication 
  pinMode(PIN_LED_RED, OUTPUT);
  pinMode(PIN_LED_GREEN, OUTPUT);
  pinMode(PIN_LED_BLUE, OUTPUT);
  pinMode(PIN_BAT1_VSENSE, INPUT);
  pinMode(PIN_BAT2_VSENSE, INPUT);
  analogReadResolution(12); 
  checkBattery();

  // Button 
  pinMode(PIN_BUTTON, INPUT_PULLUP);
  attachInterrupt(digitalPinToInterrupt(PIN_BUTTON), onButtonPress, FALLING); // Assuming active-low button

  // OLED Init
  u8g2.begin();
  displayTwoLines("OLED", "initialized!", u8g2_font_ncenB10_tr, 40, 25);
  RemoteXY_delay(2000);

  // IMU Init (Rev2)
  displayTwoLines("Initializing", "IMU...", u8g2_font_ncenB10_tr, 25, 45);
  RemoteXY_delay(2000);
  if (!IMU.begin()) {
    Serial.println("Failed to initialize IMU.");
    displayTwoLines("Failed to", "initialize IMU.", u8g2_font_ncenB10_tr, 35, 10);
    while (1);
  }
  
  RemoteXY_delay(2000);  // Remove once we make sure an ISR cant interrupt it.
  Serial.println("IMU initialized successfully!");
  displayTwoLines("IMU initialized", "successfully!", u8g2_font_ncenB10_tr, 10, 20);
  RemoteXY_delay(2000);

  displayTwoLines("Initializing", "BARO sensor...", u8g2_font_ncenB10_tr, 25, 10);
  RemoteXY_delay(2000);
  if (!BARO.begin()) {
    Serial.println("Failed to initialize pressure sensor.");
    displayTwoLines("Failed to initialize", "pressure sensor.", u8g2_font_6x10_tr, 5, 20);
    while (1);
  }
  Serial.println("BARO sensor initialized!");
  displayTwoLines("BARO sensor", "initialized!", u8g2_font_ncenB10_tr, 15, 25);
  RemoteXY_delay(2000);

  // Baro Init
  displayTwoLines("BARO sensor", "initialized!", u8g2_font_ncenB10_tr, 15, 25);
  RemoteXY_delay(2000);


  //============ ESP Initialisation  ================
  Serial.println("Waiting for ESP32 + SIM7600 to initialize...");
  displayTwoLines("Waiting for", "ESP32...", u8g2_font_ncenB10_tr, 40, 25);
  RemoteXY_delay(2000);

  pinMode(LED_PIN, OUTPUT);
  pinMode(READY_LINE, INPUT);
  pinMode(ACK_LINE, INPUT);
  attachInterrupt(digitalPinToInterrupt(READY_LINE), onESPReady, RISING);

  WireESP.begin();

  espReady = digitalRead(READY_LINE);  // Check initial state
  
  while (!espReady) {
    Serial.println("ESP32 not ready. Retrying in 3s...");
    displayTwoLines("ESP32", "not ready...", u8g2_font_ncenB10_tr, 40, 25);
    RemoteXY_delay(3000);
  }

  Serial.println("✅ ESP32 is ready. Proceeding...");
  displayTwoLines("✅ ESP32 Ready", "Proceeding ...", u8g2_font_ncenB08_tr, 0, 12);
  RemoteXY_delay(2000);
  //============ ESP Initialisation End  ================

  // GPS module on Serial1 (D0 = RX, D1 = TX)
  //Serial.println("🔍 Starting GPS reader ..."); 
  displayTwoLines("Initializing", "GPS reader...", u8g2_font_ncenB10_tr, 25, 15);
  Serial1.begin(115200); 
  while (!Serial1);
  RemoteXY_delay(2000);
  displayTwoLines("GPS started", "successfully!", u8g2_font_ncenB10_tr, 21, 20);
  RemoteXY_delay(2000);
  // waiting to get the munimum gps sat count, max wait 30 sec
  waitForGPSLock();  // comment while debuging 


  if (!SD.begin(chipSelect)) {
    Serial.println("Failed to initialize SD card.");
    displayTwoLines("Failed to ini-", "tialize SD card.", u8g2_font_6x10_tr, 25, 20);
    while (1);
  }
  Serial.println("SD card initialized successfully!");
  displayTwoLines("SD card initialized", "successfully!", u8g2_font_6x10_tr, 8, 25);
  RemoteXY_delay(2000);

  updateGPSData();
  generateFilename();

  //============ IMU CALIBIRATION. =========//
  // Accelerometer & Gyroscope, stationary
  Serial.println("IMU Calibration 1 (Acc & Gyro): Press button");
  displayTwoLines("IMU Off Calibration:", "Press button", u8g2_font_ncenB10_tr, 10, 20);
  waitForButtonPressed();
  Serial.println("Press, once again, to end calibation 1");
  displayTwoLines("End?", "Press button", u8g2_font_ncenB10_tr, 10, 20);
  waitForButtonPressed();
  
  calibrateIMU();

  // Magnetometer, victory dance!
  Serial.println("IMU Calibration 2 (Magnetometer): Press button");
  displayTwoLines("Magnet. Calibration:", "Press button", u8g2_font_ncenB10_tr, 10, 20);
  waitForButtonPressed();
  do {
    if (retryCalibration == 1) {
      Serial.println("Calibration failed... Trying again");
      displayTwoLines("CALIB FAIL...", "Trying Again", u8g2_font_ncenB10_tr, 10, 20);
    }
    calibrateIMU2();
  } while (retryCalibration);

  Serial.println("IMU calibration complete.");  
  displayTwoLines("IMU calibration", "complete.", u8g2_font_ncenB10_tr, 10, 20);
  RemoteXY_delay(2000);
  //============ IMU CALIBIRATION END. =========//

  displayTwoLines("Ready to", "start!", u8g2_font_ncenB10_tr, 35, 45);
  RemoteXY_delay(2000);
  
  displayToScreen("Team 1", 30, 35);
  RemoteXY_delay(2000);

  // Wait for button to start logging
  bool toggle = false;
  buttonInterruptFlag = false;
  while (!buttonInterruptFlag) {
    updateBatteryVoltage();

    if (battery1Voltage < BAT_VLOW || battery2Voltage < BAT_VLOW) {
      // Low battery: show warning and red LED only
      digitalWrite(PIN_LED_GREEN, LOW);
      digitalWrite(PIN_LED_RED, HIGH);
      displayToScreen("Battery LOW!", 15, 40);
    } else {
      // Battery OK: rotate display info and blink green LED
      if (millis() - lastDisplaySwitch > 2000) {  // Every 2 seconds
        lastDisplaySwitch = millis();
        displayState = (displayState + 1) % 3;

        switch (displayState) {
          case 0: // Team number
            char buf[20];
            snprintf(buf, sizeof(buf), "Team %d", TEAM_NUMBER);
            displayToScreen(buf, 25, 35);
            break;

          case 1: { // Battery level
            char buf[20];
            snprintf(buf, sizeof(buf), "%.2f V, %.2f V", battery1Voltage, battery2Voltage);
            displayTwoLines("Battery level:", buf, u8g2_font_ncenB10_tr, 15, 50);
            break;
          }

          case 2: // promte the user to start logging
            displayTwoLines("Press the button", "to start logging", u8g2_font_ncenB10_tr, 10, 30);
            break;
        }

        toggle = !toggle;
        digitalWrite(PIN_LED_GREEN, HIGH);  // Blink green LED
        digitalWrite(PIN_LED_RED, LOW);       // Red LED off when voltage is fine
        digitalWrite(PIN_LED_BLUE, toggle);       // Red LED off when voltage is fine
      }
    }
  }

}

void loop() {
  now = millis();
  digitalWrite(LED_PIN, now % 1000 < 50);  // LED heartbeat every 1 sec
  //Serial.println(espReady);
  //Serial.println(digitalRead(READY_LINE));

  if (now - lastCollectTime >= loggingPeriod)  {
    lastCollectTime = now;
    


    updateLogging();
    updateIMUData();
    attitudeInitialization();
    attitudeAngles();
    updateBarometerData();
    updateGPSData();
    log();
    //printIMUOffsetsAndReadings();
    // displayToScreen();
    // readNextLineFromSD();
    //RemoteXY_delay(1000); // 1Hz logging rate will be removed later!
    checkBattery();
    
    // UI rotation: team, battery, GPS, log state, ACK status
    if (now - lastDisplaySwitch > 2000) {
      lastDisplaySwitch = now;
      displayState = (displayState + 1) % 5;  // now 5 states total

      switch (displayState) {
        case 0:
          displayToScreen("Team 1", 25, 35);
          break;

        case 1: {
          char buf[20];
          snprintf(buf, sizeof(buf), "%.2f V, %.2f V", battery1Voltage, battery2Voltage);
          displayTwoLines("Battery1,2 level:", buf, u8g2_font_ncenB10_tr, 15, 50);
          break;
        }

        case 2:
          displayTwoLines("Satellites:", String(SatCount).c_str(), u8g2_font_ncenB10_tr, 28, 60);
          break;

        case 3: {
          const char* logStateStr = (logState == LogState::IDLE) ? "IDLE" : "Logging";
          displayTwoLines("Logging State:", logStateStr, u8g2_font_ncenB10_tr, 10, 30);
          break;
        }

        case 4: {
          // Show ACK line status from ESP
          if(I2CError == true)
          {
            displayTwoLines("I2C Error:", "need Debug", u8g2_font_ncenB10_tr, 40, 25);
            break;  // for readability 
          }
          else{
            bool ackHigh = digitalRead(ACK_LINE) == HIGH;
            displayTwoLines("ACK Line:", ackHigh ? "✅ HIGH" : "LOW", u8g2_font_ncenB10_tr, 30, 30);
            //if (ackHigh) Serial.println("✅ ACK received from ESP");
            break;
          }
        }
      }
    }
  }
  // Optional: add a short RemoteXY_delay to reduce CPU load if needed
 // RemoteXY_delay(1000); // (uncomment if display flickers or CPU usage is high)
}

// === IMU Data Update ===
void updateIMUData() {  
  if (IMU.accelerationAvailable()) {
    IMU.readAcceleration(preAccX, preAccY, preAccZ);
    accX = preAccX - accX_off;
    accY = preAccY - accY_off;
    accZ = preAccZ - accZ_off;
  }
  if (IMU.gyroscopeAvailable()) {
    IMU.readGyroscope(preGyroX, preGyroY, preGyroZ);
    gyroX = preGyroX - gyroX_off;
    gyroY = preGyroY - gyroY_off;
    gyroZ = preGyroZ - gyroZ_off;
  }
  if (IMU.magneticFieldAvailable()) {
    IMU.readMagneticField(preMagX, preMagY, preMagZ);
    magX = preMagX - magX_off;
    magY = preMagY - magY_off;
    magZ = preMagZ - magZ_off;
  }
}

// === Barometer Data Update ===
void updateBarometerData() {
  pressure = BARO.readPressure(); // in kPa
  paltitude = 44330 * (1 - pow(pressure / 101.325, 1 / 5.255));
}

// === OLED Display === For short messages
void displayToScreen(const char str[], u8g2_uint_t x, u8g2_uint_t y) {
  u8g2.clearBuffer();
  u8g2.setFont(u8g2_font_ncenB14_tr);   // u8g2_font_ncenB14_tr big size -- u8g2_font_ncenB10_tr IS OK // TOO SMALL u8g2_font_5x8_tr
  u8g2.setCursor(x, y);                 // Centered: (25, 35) -- Starting from the left: (0, 35)
  u8g2.print(str);
  u8g2.sendBuffer();
}

// === OLED Display === In two lines 
void displayTwoLines(const char line1[], const char line2[], const uint8_t* font, u8g2_uint_t x1, u8g2_uint_t x2) { // x1: x-axis position 1st line.  x2: x-axis position 2nd line.
  u8g2.clearBuffer();
  u8g2.setFont(font);
  u8g2.setCursor(x1, 25);  // Y1 = 25 for first line (adjust as needed)
  u8g2.print(line1);
  u8g2.setCursor(x2, 50);  // Y2 = 50 for second line (25+line height)
  u8g2.print(line2);
  u8g2.sendBuffer();
}

// === Read Next Line from SD ===
void readNextLineFromSD() {
  static int lineNumber = 0;
  dataFile = SD.open(filename);
  if (!dataFile) {
    Serial.println("Error opening log.csv for reading.");
    return;
  }

  int currentLine = 0;
  String line = "";

  while (dataFile.available()) {
    line = dataFile.readStringUntil('\n');
    if (currentLine == lineNumber) {
      Serial.print("Line ");
      Serial.print(lineNumber);
      Serial.print(": ");
      Serial.println(line);
      lineNumber++;
      break;
    }
    currentLine++;
  }

  dataFile.close();
}

// === Barometer Data Update ===
void updateGPSData() {
    while (Serial1.available()) {
      char c = Serial1.read();

      // Print raw NMEA sentence
      //Serial.write(c);

      // Feed to TinyGPS parser
      gps.encode(c);
    
      SatCount = gps.satellites.value();

  // Show satellite count every ~1s
  //  if (millis() % 1000 < 50) {
  //    Serial.print("\n Satellites count: ");
  //    Serial.println(gps.satellites.value());
  //    displayTwoLines("Satellites count: ", String(SatCount).c_str(), u8g2_font_ncenB10_tr, 5, 20);
  //  }

    if (gps.location.isUpdated()) {
      latitude     = gps.location.lat();
      longitude    = gps.location.lng();
      gpsAltitude  = gps.altitude.meters();
      Speed        = gps.speed.kmph();
      SatCount     = gps.satellites.value();

      // Serial.println("\n✅ Parsed GPS Data:");
      // Serial.print("Latitude: "); Serial.println(latitude, 6);
      // Serial.print("Longitude: "); Serial.println(longitude, 6);
      // Serial.print("Satellites: "); Serial.println(SatCount);
      // Serial.print("Speed (km/h): "); Serial.println(Speed);
      // Serial.print("Altitude (m): "); Serial.println(gpsAltitude);
      // Serial.println("----------------------");
    }
  }
}

// === Updates current battery voltage ===
void updateBatteryVoltage(){
  battery1Voltage = analogRead(PIN_BAT1_VSENSE) * VREF / ADC_MAX / (R1 /(R1 + R2)); //
  battery2Voltage = analogRead(PIN_BAT2_VSENSE) * VREF / ADC_MAX / (R1 /(R1 + R2)); //
  //Serial.println(analogRead(PIN_BAT1_VSENSE) );
  //Serial.println(battery1Voltage);
}

// === Checks battery charging need ===
void checkBattery(){
  updateBatteryVoltage();

  if(battery1Voltage < BAT_VLOW || battery2Voltage < BAT_VLOW){ //!!!check LED connection for HIGH/LOW assignment
    digitalWrite(PIN_LED_GREEN, LOW);
    digitalWrite(PIN_LED_RED, HIGH);
  } else {
    digitalWrite(PIN_LED_RED, LOW);
    digitalWrite(PIN_LED_GREEN, HIGH);
  }
}

// // === Check if button is pressed and released ===
// bool buttonReleased() {
//   reading = digitalRead(PIN_BUTTON);
//   // Serial.println(lastStableState);
//   // Serial.println(lastEdge);

//   if (reading != lastStableState && (millis() - lastEdge) > DEBOUNCE_MS) {
//     lastEdge = millis();
//     if (lastStableState == LOW && reading == HIGH) {
//       lastStableState = reading;
//       Serial.println("Button Pressed. logging starting...");
//       return true; // button pressed
//     }
//     lastStableState = reading;
//   }  
//   return false;
// }
// interuupt servive routine to set the flag button pressed! if the press happened (falling edge) > 200 ms , button is active
void onButtonPress() { 
  if (millis() - lastEdge > DEBOUNCE_MS) {
    buttonInterruptFlag = true;
    lastEdge = millis();
  }
}

void waitForButtonPressed() {
  while (!buttonInterruptFlag && (RemoteXY.PushButton != 1)) {
    RemoteXY_Handler ();
    updateGuiInfo();
    RemoteXY_delay(5);
  }
  buttonInterruptFlag = false; 
}
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

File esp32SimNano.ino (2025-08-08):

#include <Wire.h>

#define I2C_ADDRESS    0x42
#define STATUS_LED     2 
#define READY_LINE     4   // ESP32 ➝ Nano
#define ACK_LINE       5   // ESP32 ➝ Nano
#define SIM_BAUD 115200
#define SIM_TX 17  // TX to SIM7600 RX
#define SIM_RX 16  // RX from SIM7600 TX
#define SEND_INTERVAL  200  // ms (time between I2C receive and ACK)

HardwareSerial SIM7600(2);

enum Mode { REALTIME, BATCH };
Mode currentMode = REALTIME;  // Default mode

String latestPayload = "";
String lastResponse = "";

bool dataHasBeenReceived = false;
bool simReady = false;

unsigned long now = 0;
unsigned long lastAttemptTime = 0;
unsigned long lastSIMCheckTime = 0;

// ====== I2C RECEIVE CALLBACK ======
void receiveEvent(int howMany) {
  if (howMany < 2) return;

  digitalWrite(READY_LINE, LOW);  // 🛑 Not ready while receiving

  latestPayload = "";
  while (Wire.available()) {
    latestPayload += (char)Wire.read();
  }

  dataHasBeenReceived = true;

  // 🔍 Look for mode in JSON payload
  if (latestPayload.indexOf("\"mode\":\"REALTIME\"") != -1) {
    currentMode = REALTIME;
    //Serial.println("🌀 Mode: REALTIME");
  } else if (latestPayload.indexOf("\"mode\":\"BATCH\"") != -1) {
    currentMode = BATCH;
    //Serial.println("🌀 Mode: BATCH");
  } else {
    //Serial.println("⚠️ Could not determine mode from payload.");
  }

  //Serial.println("✅ Payload received:");
  //Serial.println(latestPayload);
}

void setup() {
  Serial.begin(115200);
  delay(1000);

  pinMode(STATUS_LED, OUTPUT);
  pinMode(READY_LINE, OUTPUT);
  pinMode(ACK_LINE, OUTPUT);

  digitalWrite(READY_LINE, LOW);
  digitalWrite(ACK_LINE, LOW);

  Wire.begin(I2C_ADDRESS);  // ESP32 as I2C Slave
  Wire.onReceive(receiveEvent);

  delay(2000);
  initSIM7600();
  Serial.println("✅ ESP32 I2C Slave ready");
}

void loop() {
  now = millis();

  // Blinking status LED (heartbeat)
  digitalWrite(STATUS_LED, now % 1000 < 50);

  if (dataHasBeenReceived && (now - lastAttemptTime >= SEND_INTERVAL)) {
    dataHasBeenReceived = false;

    //Serial.println("[ESP] 📨 Forwarding payload:");
    //Serial.println(latestPayload);

    // Simulated send to SIM7600 here
    // bool ok = sendPayload(latestPayload);
    bool ok =  sendPayload(latestPayload);  // Placeholder for real send

    if (ok) {
      //Serial.println("[ESP] ✅ Payload processed!");
      digitalWrite(ACK_LINE, HIGH);
    } else {
    //  Serial.println("[ESP] ❌ Send failed");
      digitalWrite(ACK_LINE, LOW);
    }

    lastAttemptTime = now;
    latestPayload = "";
  }

  // SIM status check every SEND_INTERVAL mm sec
  if (now - lastSIMCheckTime >= SEND_INTERVAL ) {
    simReady = checkSIMStatus();
    digitalWrite(READY_LINE, simReady ? HIGH : LOW);
    lastSIMCheckTime = now;
  }
}



// ====== INIT SIM7600 ======
int initSIM7600() {
  SIM7600.begin(SIM_BAUD, SERIAL_8N1, SIM_RX, SIM_TX);
  Serial.println("[SIM7600] Waiting for module...");

  // Keep sending AT until OK
  while (!sendAT("AT", "OK", 1000)) {
    Serial.println("[SIM7600] No AT response. Retrying...");
    delay(1000);
  }

  Serial.println("[SIM7600] AT responded. Proceeding with initialization...");

  // --- ATE0 ---
  if (!sendAT("ATE0", "OK", 1000)) {
    Serial.println("[SIM7600] Failed to disable echo (ATE0).");
    return 1;
  }

  // --- NETOPEN ---
  if (!sendAT("AT+NETOPEN", "OK", 5000)) {
    if (lastResponse.indexOf("+IP ERROR:") != -1) {
      Serial.println("[SIM7600] Network already open. Continuing...");
    } else {
      Serial.println("[SIM7600] Failed to open network.");
      return 2;
    }
  }

  // --- HTTPINIT ---
  if (!sendAT("AT+HTTPINIT", "OK", 2000)) {
    Serial.println("[SIM7600] HTTPINIT failed. Attempting HTTPTERM recovery...");
    if (sendAT("AT+HTTPTERM", "OK", 2000)) {
      Serial.println("[SIM7600] HTTP session terminated. Retrying HTTPINIT...");
      if (!sendAT("AT+HTTPINIT", "OK", 2000)) {
        Serial.println("[SIM7600] HTTPINIT failed again.");
        return 3;
      }
    } else {
      Serial.println("[SIM7600] HTTPTERM failed. Cannot proceed.");
      return 3;
    }
  }

  // --- Set URL ---
  if (!sendAT("AT+HTTPPARA=\"URL\",\"http://shiro11.pythonanywhere.com/data\"", "OK", 2000)) {
    Serial.println("[SIM7600] Failed to set HTTP URL.");
    return 4;
  }

  // --- Set content type ---
  if (!sendAT("AT+HTTPPARA=\"CONTENT\",\"application/json\"", "OK", 2000)) {
    Serial.println("[SIM7600] Failed to set content type.");
    return 4;
  }

  Serial.println("[SIM7600] Initialization successful.");
  simReady = true;
  digitalWrite(READY_LINE, HIGH);  // Signal Nano that we're ready

  return 0;
}


// ====== SEND PAYLOAD ======
bool sendPayload(const String& payload) {
  if (!sendAT("AT+HTTPDATA=" + String(payload.length()) + ",10000", "DOWNLOAD", 3000)) return false;

  SIM7600.println(payload);
  SIM7600.flush();

  if (!waitFor("OK", 3000)) return false;
  
  if (sendAT("AT+HTTPACTION=1", "+HTTPACTION: 1,200", 5000)) return true;
  return false;
}


// ====== WAIT FOR TARGET ======

bool waitFor(String expected, int timeout) {
  unsigned long t0 = millis();
  String buffer = "";

  while (millis() - t0 < timeout) {
    while (SIM7600.available()) {
      char c = SIM7600.read();
      buffer += c;
      Serial.write(c);  // Optional: print for debugging
    }

    if (buffer.indexOf(expected) != -1) {
      return true;
    }
  }

 // Serial.println("[SIM7600] Timeout waiting for (waitFor): " + expected);
  return false;
}


// ====== SEND AT & WAIT FOR TARGET ======
bool sendAT(String cmd, String expected, int timeout) {
  SIM7600.println(cmd);
  unsigned long t0 = millis();
  lastResponse = "";  // capture new response

  while (millis() - t0 < timeout) {
    while (SIM7600.available()) {
      char c = SIM7600.read();
      lastResponse += c;
      Serial.write(c);  // Optional: debug output
    }
    if (lastResponse.indexOf(expected) != -1) return true;
  }

  //Serial.println("[SIM7600] Timeout waiting for: " + expected);
  return false;
}

//====== Check if SIM still alive ======
bool checkSIMStatus() {
  return sendAT("AT", "OK", 1000);
}

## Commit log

2025-05-28 Add wiring diagram
    Missing step-up converter connections to Arduino.
2025-05-28 Add wiring diagram to README.md
2025-05-28 Update wiring diagram
    Changes to step-up converter and R2 connections.
2025-05-28 Update README
    Update wiring diagram link in README
2025-05-30 Uploaded initial documentation
    [Datalogger.xlsx]
2025-05-31 Update DataLogger_2025.ino
    - Update functions for OLED display.
    - Add loop to OLED display after initiation.
    - Add global variable for battery level.
2025-06-06 Update wiring diagram
    - Add LEDs circuit part.
    - Add capacitors for SD card reader.
    - Add common Ground and common Vcc lines for components.
    - Modify voltage divider resistance value.
2025-06-06 Update README
    - Update attached link to wiring diagram.
2025-06-11 Update DataLogger_2025.ino
    Median Filter implemented for calibration of the IMU.
    Next steps:
    - Calibrating the Magnetometer (this week)
    - Improving the reliability taking ISR interruptions into account. Once this point is achieved for key code areas, display messages can be removed saving initialization time.
    What's a median filter and why using it improves the performance?
    Example:
    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
2025-06-16 Uploaded "A03 Magnetometer Analysis"
    Using sample data from public flights, an offline Kalman Filter is tested to remove hard-iron and soft-iron offsets from the magnetometer. It is the stepstone of a final version that will be used to test the best calibration method.
    This program must be tested using different positions of the plane to understand what is the most efficient calibration procedure. Possible alternatives include:
    - Real-time calibration (doesn't seem the most effective, proven in this data study)
    - 360 degrees rotations before the start of the flight (potential solution)
    - 3D 360 degrees rotations (unpractical for medium size planes)
    [testingDoc1_sensor_mag_0.csv, testingDoc1_sensor_mag_1.csv, testingDoc2_sensor_mag_0.csv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]
2025-06-18 Convolution Filter Testing
    Testing different ways to handle the edges for the convolution filter. Test_4.py and Test_5.py are promising
2025-06-18 Update calibration program in .ino
    Polished my previous commit regarding the IMU calibration:
    - Fixed inefficiencies such as the offsets calculated inside the loop
    - Fixed the variable name mistake in accXCalibBuffer[CALIB_SAMPLES];
    - Avoided a busy-loop in "while (!IMU.accelerationAvailable() || !IMU.gyroscopeAvailable())"
    - Fixed two typos in "while(!IMU.accelerationAvailable() || !IMU.gyroscopeAvailable()));"
    Potential future patches:
    - "paltitude = 44330 * (1 - pow(pressure / 101.325, 1 / 5.255));" should make an integer division (integer) / (float). Consider this effect and maybe add 1.0 / 5.255?
    [DataLogger_2025.ino]
2025-06-22 Update DataLogger_2025.ino
    Shiro: new data logger version
    -- Luciano´s imu calibration included
    -- interrupt of the button implemented
    -- gps ready state added
    -- logging state update
2025-06-27 Final MATLAB Magnetometer analysis + restructured folders and README files
    [Datalogger.xlsx, testingDoc1_sensor_mag_0.csv, testingDoc1_sensor_mag_1.csv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]
2025-06-28 Calibration methods: Full Kalman / Six-Axis / Two-Axis
    [testingDoc1_sensor_mag_0.csv, testingDoc1_sensor_mag_1.csv, testingDoc2_sensor_mag_0.csv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]
2025-06-28 Update DataLogger_2025.ino Magnetometer Calibration
    Magnetometer calibration program assuming we use a Two-Axis calibration procedure (all described inside the MATLAB folder).
    I will continue adding refinements during the week.
2025-07-17 Create esp32SimNano.ino
    This is a new firmware to the esp32 module. this module is sued to receive the data from arduino nano over I2C as chunks. then send it to sim7600 to the server
2025-07-18 Update DataLogger_2025.ino
    adding the missing semi column from the last PR!
    [DataLogger_2025.ino]
2025-08-04 Completed implementation of Gaussian and Softmax GPS filters.
    Test 10 - Program to simulate live sensor data and feed into Gaussian filter.
    Test 11 - Program to simulate live GPS sensor data and feed into Softmax GPS filter.
    TimeTest - Program to measure performance of both filters.
    [Datalogger.xlsx, T0122064.CSV]
2025-08-05 Simplified magnetometer test program update: adapted to current commits and enhanced logic
2025-08-05 Magnetometer test-program update
2025-08-06 Update .ino (Magnetometer calibration)
    Completed the Magnetometer calibration, prepared for 6-Axis method. After calibration, magX, magY, magZ are NOT zero.
    - Included constants, such as "CALIB_SAFETY_CHECK", logic and functions for debugging and quality-check purposes.
    @Shiro-01, the code was tested on a simplified version, although I couldn't run the whole application due to the <CircularBuffer.hpp> dependency. Everything should work as expected in the complete pr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
    Future steps:
    - Calculate roll, yaw, and pitch and make sure the readings are reliable after calibration (I'm very interested on inspecting this).
    - Consider a Kalman real-time filter to account for the distortio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
2025-08-13 Bluetooth Control
    @Shiro-01 I attach you as a reviewer of this commit for you to test the program with the full prototype. However, the changes are done mostly in a safe way with the use of the macro "WITH_BLUETOOTH", and I am merging the branch to save your reviewing time and avoid outdated pull requests.
    The code implements BLE functionalities without the use of the mentioned RemoteXY library, which would interfere with some natural RTOS functions. A downside may be limited GUI, but this achieves simple and flexible functionality that can easily be extended to future needs.
    How to connect with the program?
    1) Download "nRF Connect" compatible with iOS and Android
    2) Connect with de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
    [DataLogger_2025.ino]
2025-08-14 Modularization of DataLogger_2025.ino for better maintainability and future expansion. (Still to be tested with the complete prototype)
2025-08-16 Main program update: Simplified attitude calculation
    Well working program, using simple sensor fusion logic. Achieves the expected results.
2025-08-19 Update esp32SimNano.ino
    adding remotexy
2025-08-19 Revert "Update esp32SimNano.ino"
    This reverts commit 53f1844ccb404ec4c66f032d9cbfcc5e10778e0f.
    [esp32SimNano.ino]
2025-08-20 Main program: Kalman Filter + Payload update
2025-08-20 Necessary libraries for on-device Kalman Filter
    Source: https://github.com/TKJElectronics/KalmanFilter
    In order to run in the Arduino IDE, change from #include <Kalman.h> to #include "Kalman.h"
2025-08-26 Digital Flight Tracker for post-competion evaluation
    [flight1.CSV, flight2.CSV, flight3.CSV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]
2025-10-24 Datalogger schematic
    - Add updated schematic
2025-10-24 Create folder
    Create folder for PCB files
    [Datalogger_schematic.kicad_sch]
2025-10-24 Upload files
    Upload datalogger project files
    [Datalogger_schematic.kicad_pcb, Datalogger_schematic.kicad_sch]
